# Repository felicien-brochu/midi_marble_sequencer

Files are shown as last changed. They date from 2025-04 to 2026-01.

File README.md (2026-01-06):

# MIDI Marble Sequencer

MIDI Marble Sequencer is a hardware + firmware project that detects marbles on IR sensor tracks and outputs MIDI over USB. The system is split into a main ESP-IDF firmware (sequencer + USB MIDI) and ESP32-based control boards (Arduino/PlatformIO) connected over I2C.

## Repository layout

- `hardware/` — CAD (SolidWorks parts/assemblies) and related manufacturing files.
- `software/`
	- `midi_marble_sequencer_main/` — main firmware (ESP-IDF) for the sequencer + USB MIDI.
	- `midi_marble_sequencer_controls_main/` — main control board firmware (PlatformIO/Arduino).
	- `midi_marble_sequencer_controls_pages/` — pages control board firmware (PlatformIO/Arduino).
	- `common_src/` — shared code used by the control board firmwares.
	- `smab_midi_mapper/` — JUCE utility app (see its README).
	- `stats/` — calibration/statistics data exports.

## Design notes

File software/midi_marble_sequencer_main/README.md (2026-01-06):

# MIDI Marble Sequencer — firmware (main)

Compact firmware for the MIDI Marble Sequencer. Runs on ESP-IDF and exposes a USB MIDI device while controlling sensor boards, control boards, and a sequencer engine.

## Highlights
- Real-time sequencer with 8 tracks × 32 eighth-note positions
- IR sensor-based marble color detection and calibration
- USB MIDI output via TinyUSB
- Control boards over I2C (main controls + pages)
- Calibrate IR sensors via dedicated calibration mode

## Requirements
- ESP-IDF v5.x
- C/C++ toolchain supported by ESP-IDF (esp-clang / xtensa)
- USB host supporting TinyUSB (configured in project)
- Connected hardware: IR sensor boards, control boards, calibration button, LEDs

Repo uses component manifest: espressif/esp_tinyusb and idf ^5.0

## Build & Flash (typical)
1. Install ESP-IDF v5 and toolchain following Espressif instructions.
2. From firmware directory (where this README.md lives):
    - idf.py build
    - idf.py -p /dev/ttyUSB0 flash monitor
    Replace serial port as needed.

## Calibration mode
To enter calibration:
1. Power OFF the device.
2. Power ON while holding the calibration button (back of the device).
3. Release the button when the device boots into calibration mode.

See calibration_README.md for detailed step-by-step instructions and measurement patterns.

## Usage
- Plug device into a host — it appears as a MIDI device.
- Use the hardware controls (play/pause, BPM potentiometer, page buttons, rotary buttons) to control playback and editing.
- Sequencer state and controls are managed by ControlBoardsController and Sequencer classes; MIDI mapping is handled by MidiMapper.

## Project layout (main)
- main/
  - Sequencer.* — sequencer logic and page management
  - MasterClock.* — timing and scheduling
  - MarbleDetector.* — detect marbles using thresholds
  - MidiController.*, MidiMapper.* — MIDI output and mapping
  - ControlBoardsController.* — I2C communications with control boards
  - calibration/ — calibration controller, display, storage, stats
  - IRSens* — IR sensor reading utilities
  - CMakeLists.txt, idf_component.yml, README.md

## Contributing
- Open PRs against main branch.
- Keep firmware changes modular and test with hardware where possible.

## License
Add a license file to the repo (e.g., MIT) if desired.

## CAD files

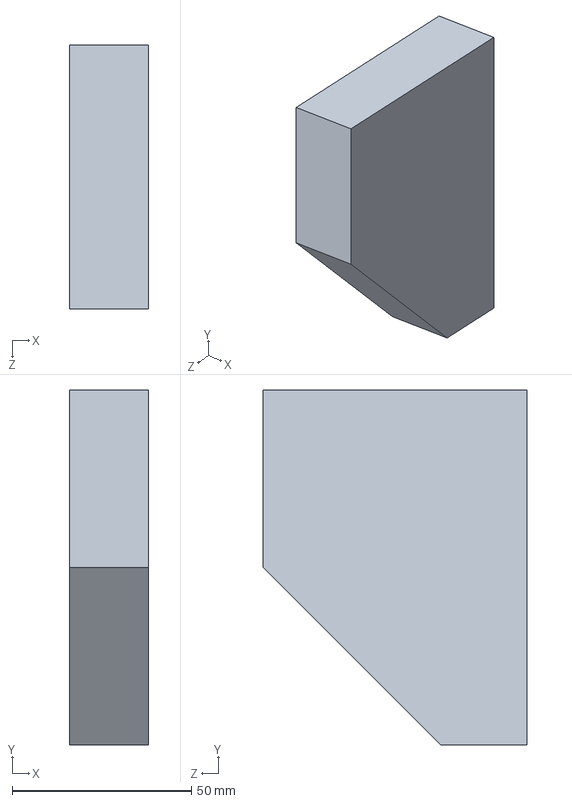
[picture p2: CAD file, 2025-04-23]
hardware/box/Equerre_trav_int_horiz_arriere^MIDI_marble_sequencer_box_Assemblage.SLDPRT
22.0 x 99.0 x 73.5 mm

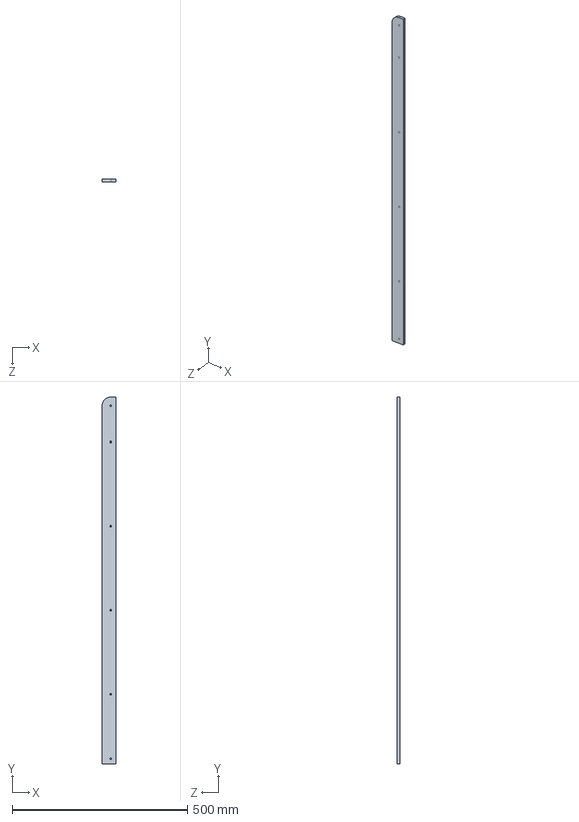
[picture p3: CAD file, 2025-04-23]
hardware/box/planche_avant^MIDI_marble_sequencer_box_Assemblage.SLDPRT
40.0 x 1047.5 x 8.00 mm

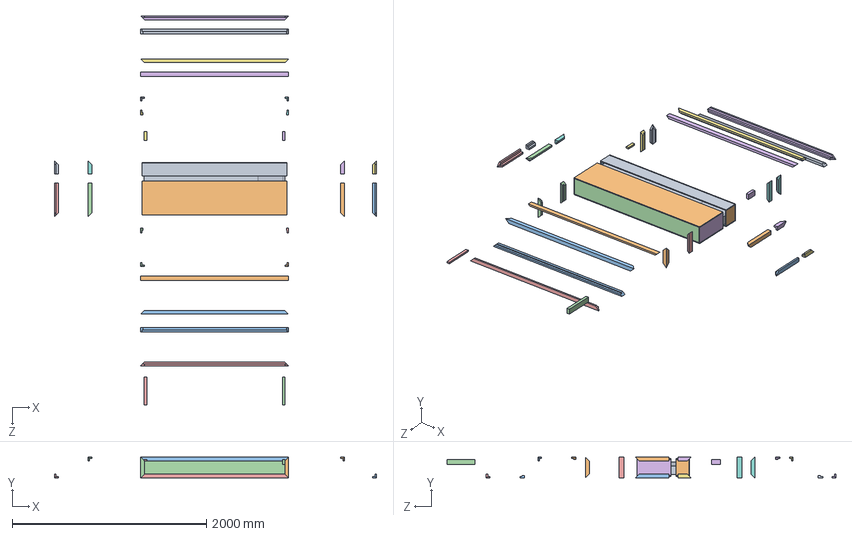
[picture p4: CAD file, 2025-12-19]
hardware/flightcase/midi_marble_sequencer_flight_case.SLDASM
3318.9 x 216.0 x 4009.3 mm
sequencer_dummy^midi_marble_sequencer_flight_case
corniere_av_m_av_d
corniere_av_l_av_h
corniere_av_m_av_g
corniere_av_l_av_b
corniere_ar_l_ar_b
corniere_ar_l_ar_h
corniere_ar_m_ar_d
corniere_ar_m_ar_g
bord_av_l_ar_h^midi_marble_sequencer_flight_case
bord_av_l_ar_b^midi_marble_sequencer_flight_case
bord_av_m_ar_g
bord_av_m_ar_d^midi_marble_sequencer_flight_case
bord_ar_l_av_h^midi_marble_sequencer_flight_case
bord_ar_m_av_g^midi_marble_sequencer_flight_case
bord_ar_m_av_d^midi_marble_sequencer_flight_case
bord_ar_l_av_b^midi_marble_sequencer_flight_case
corniere_arrete_av_t_d_h
corniere_arrete_av_t_d_b
corniere_arrete_av_t_g_h
corniere_arrete_av_t_g_b
corniere_arrete_ar_t_d_h
corniere_arrete_ar_t_d_b
corniere_arrete_ar_t_g_h
corniere_arrete_ar_t_g_b
panneau_av_h^midi_marble_sequencer_flight_case
panneau_av_b^midi_marble_sequencer_flight_case
panneau_av_av^midi_marble_sequencer_flight_case
panneau_av_g^midi_marble_sequencer_flight_case
panneau_av_d^midi_marble_sequencer_flight_case
panneau_ar_ar^midi_marble_sequencer_flight_case
panneau_ar_b^midi_marble_sequencer_flight_case
panneau_ar_h^midi_marble_sequencer_flight_case
panneau_ar_d^midi_marble_sequencer_flight_case
panneau_ar_g^midi_marble_sequencer_flight_case
maintien_av_d^midi_marble_sequencer_flight_case
maintien_av_g^midi_marble_sequencer_flight_case
maintien_ar_g^midi_marble_sequencer_flight_case
maintien_ar_d^midi_marble_sequencer_flight_case

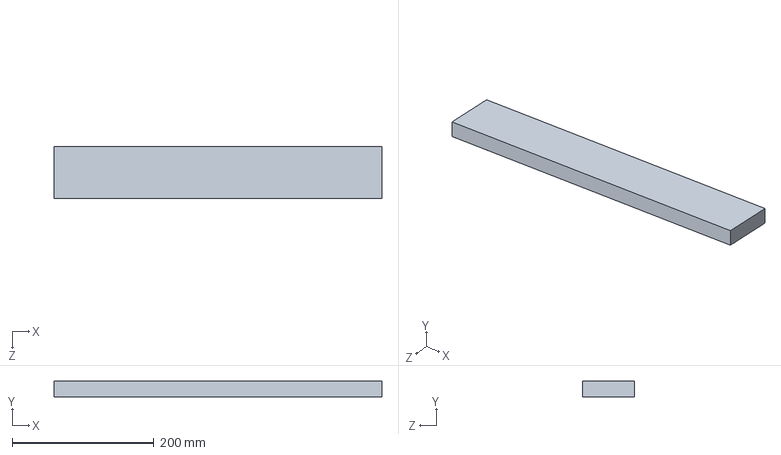
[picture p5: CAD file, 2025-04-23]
hardware/box/traverse_bac_a_bille_gauche^MIDI_marble_sequencer_box_Assemblage.SLDPRT
462.0 x 22.0 x 73.5 mm

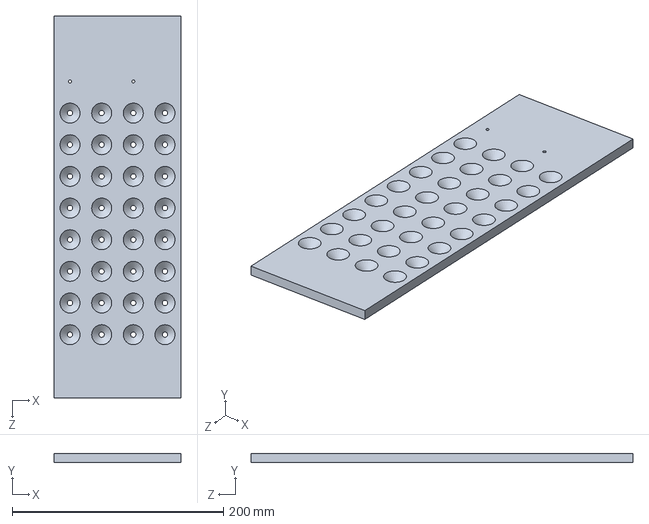
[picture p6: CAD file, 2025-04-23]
hardware/box/Planche_capteurs^MIDI_marble_sequencer_box_Assemblage.SLDPRT
120.0 x 8.50 x 362.0 mm

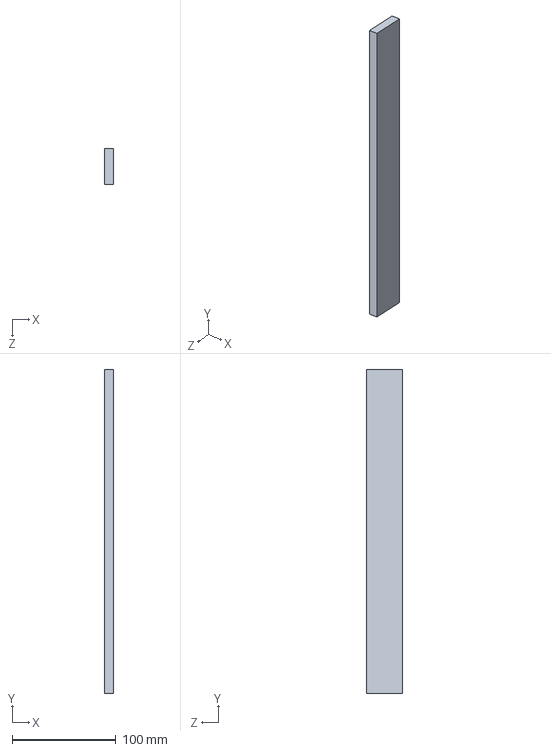
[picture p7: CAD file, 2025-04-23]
hardware/box/traverse_planche_capteurs^MIDI_marble_sequencer_box_Assemblage.SLDPRT
9.00 x 312.0 x 35.0 mm

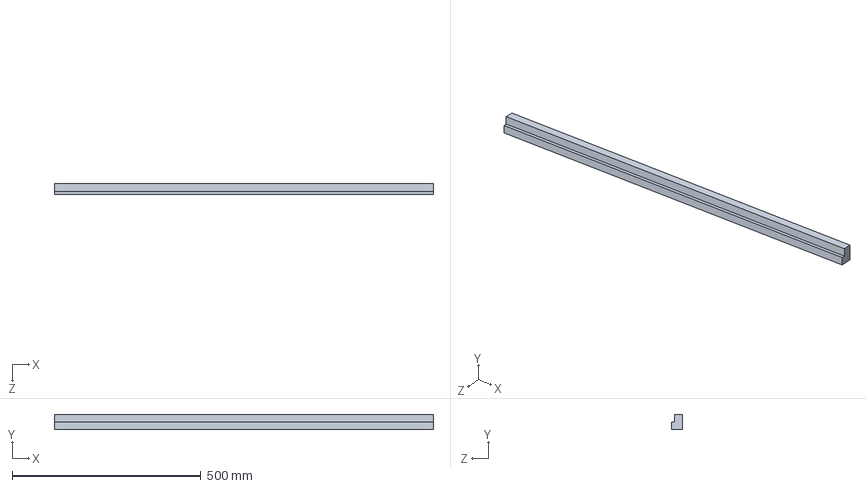
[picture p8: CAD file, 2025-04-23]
hardware/box/feuillure_avant^MIDI_marble_sequencer_box_Assemblage.SLDPRT
1005.0 x 40.0 x 30.0 mm

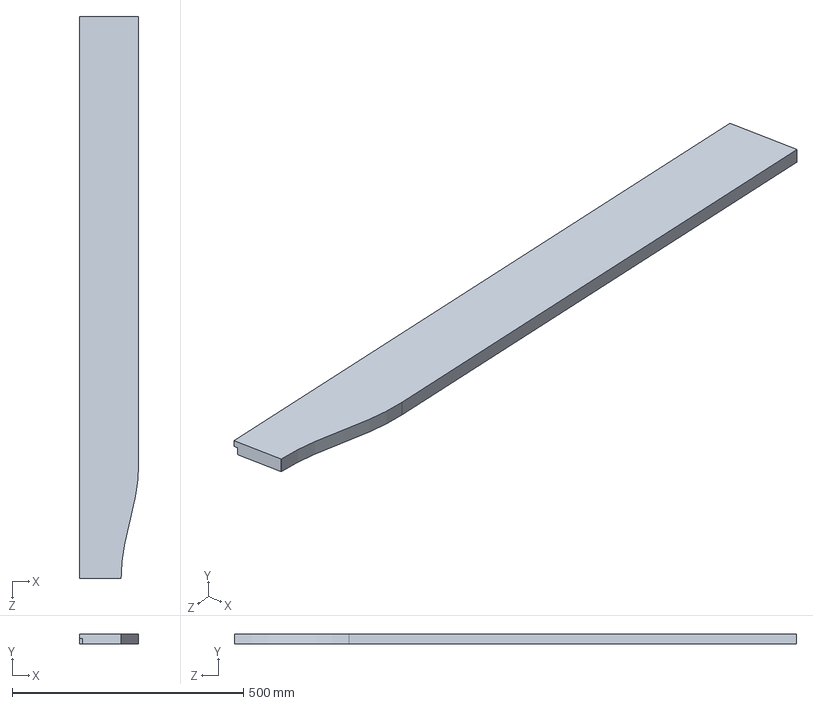
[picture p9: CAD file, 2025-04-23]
hardware/box/traverse_ext_arrière^MIDI_marble_sequencer_box_Assemblage.SLDPRT
128.5 x 22.0 x 1216.0 mm

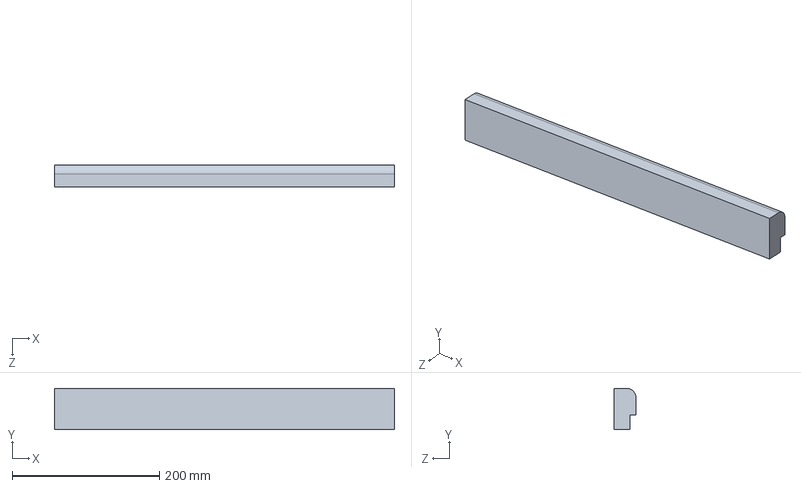
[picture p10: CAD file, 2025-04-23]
hardware/box/traverse_ext_feuillure_droite^MIDI_marble_sequencer_box_Assemblage.SLDPRT
462.0 x 56.0 x 30.0 mm

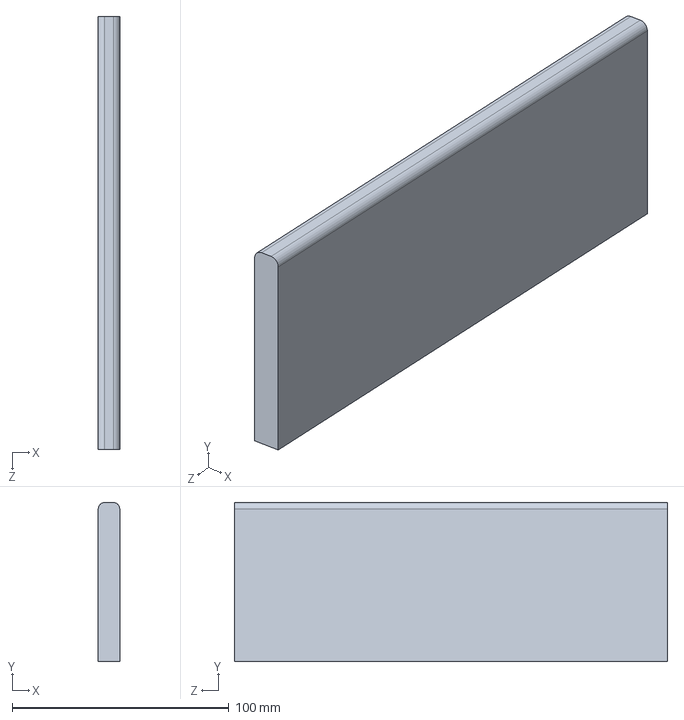
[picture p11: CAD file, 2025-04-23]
hardware/box/bac_a_billes_traverse_horiz^MIDI_marble_sequencer_box_Assemblage.SLDPRT
10.00 x 73.5 x 200.0 mm

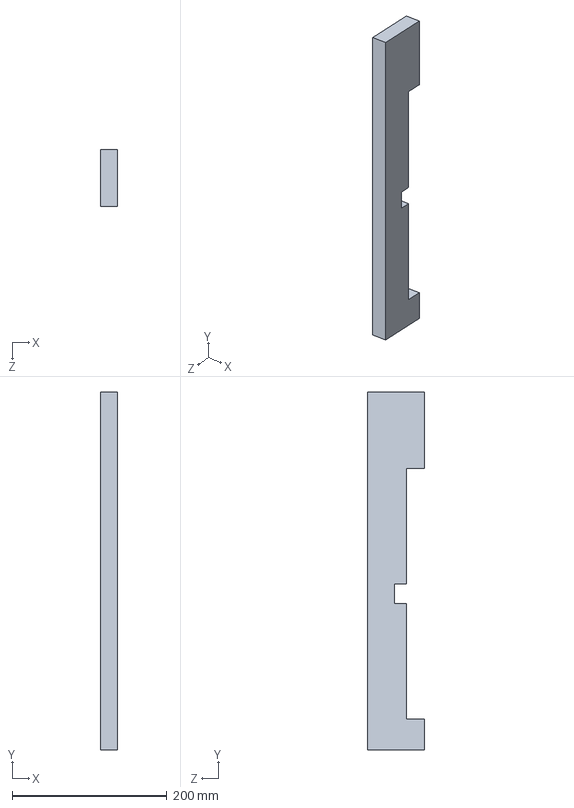
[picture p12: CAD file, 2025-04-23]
hardware/box/Copie de traverse_int_vert_gauche_vraie_traverse^MIDI_marble_sequencer_box_Assemblage.SLDPRT
22.0 x 462.0 x 73.5 mm

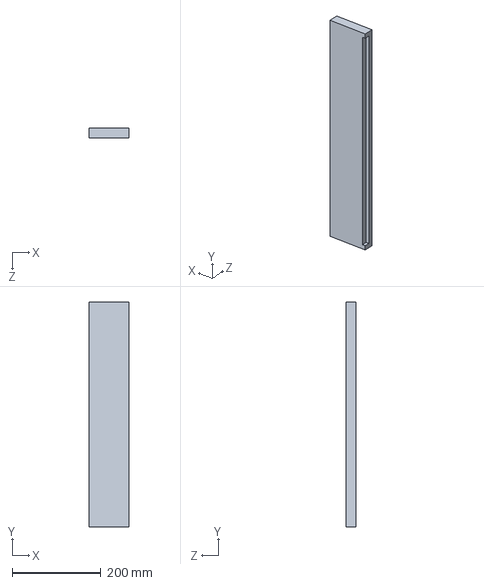
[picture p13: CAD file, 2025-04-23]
hardware/box/traverse_ext_droite^MIDI_marble_sequencer_box_Assemblage.SLDPRT
90.5 x 506.0 x 22.0 mm

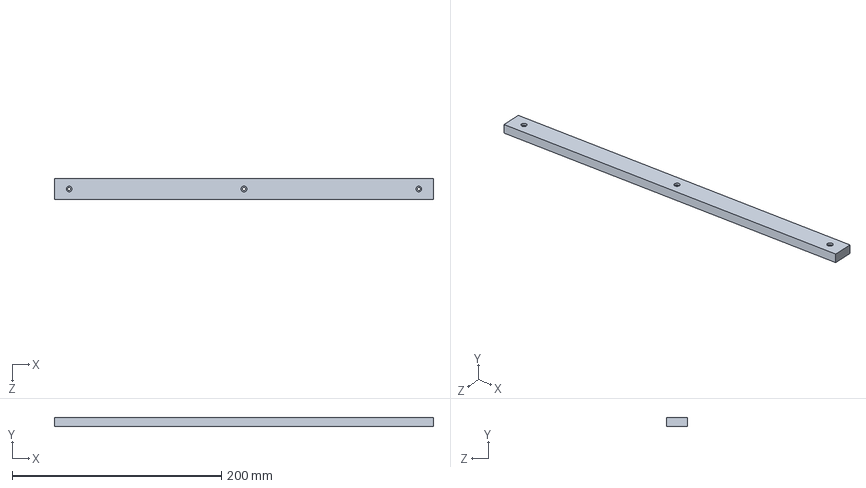
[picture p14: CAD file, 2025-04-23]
hardware/box/rallonge_droite^MIDI_marble_sequencer_box_Assemblage.SLDPRT
362.0 x 8.50 x 20.0 mm

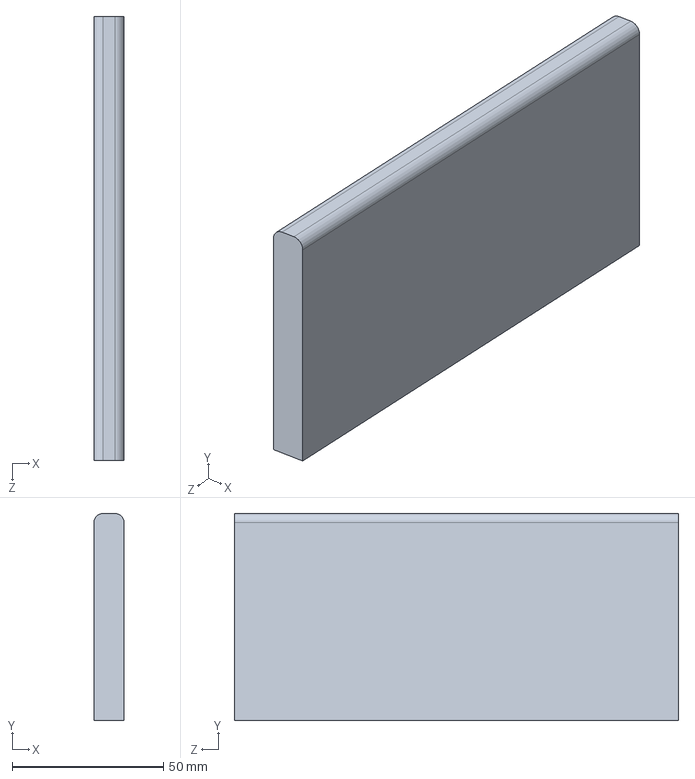
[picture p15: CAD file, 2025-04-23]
hardware/box/bac_a_billes_traverse_vert^MIDI_marble_sequencer_box_Assemblage.SLDPRT
10.00 x 68.5 x 147.0 mm

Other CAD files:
hardware/box/PCB_main.SLDPRT
hardware/box/feuillure_gauche_longue^MIDI_marble_sequencer_box_Assemblage.SLDPRT
hardware/box/traverse_arrière_int^MIDI_marble_sequencer_box_Assemblage.SLDPRT
hardware/box/traverse_int_vert_gauche_vraie_traverse^MIDI_marble_sequencer_box_Assemblage.SLDPRT
hardware/box/Bouton_BPM.SLDPRT
hardware/box/Bouton_buis_cylindre.SLDPRT
hardware/box/Bouton_play_stop.DXF
hardware/box/Bouton_play_stop.SLDPRT
hardware/box/Cadre_gauche.SLDDRW
hardware/box/Cadre_gauche^MIDI_marble_sequencer_box_Assemblage.SLDPRT
hardware/box/Débit général structure.SLDDRW
hardware/box/MIDI_marble_sequencer_box_Assemblage.SLDASM
hardware/box/PCB_channel_select.SLDPRT
hardware/box/PCB_control.SLDPRT
hardware/box/PCB_ir_sensor_board.SLDPRT
hardware/box/PCB_tracks_select.SLDPRT
hardware/box/Planche_capteurs^MIDI_marble_sequencer_box_Assemblage.SLDDRW
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

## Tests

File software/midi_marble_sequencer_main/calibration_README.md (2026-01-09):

# Calibration Procedure

This guide explains how to calibrate the IR sensors for the MIDI Marble Sequencer.

## Overview

The calibration process measures the IR sensor response for different marble colors to establish accurate detection thresholds. This ensures reliable marble detection during operation.

## Starting Calibration Mode

1. **Power off** the device
3. **Power on** the device while **holding the calibration button** (the calibration button is at the back of the sequencer)
4. **Release** the button once the device starts

The device will enter calibration mode instead of normal operation.

## Board Calibration Phase

Before the main sensor calibration begins, you'll need to complete a board calibration phase. This phase ensures that all IR sensor boards have their potentiometers properly adjusted for optimal performance.

### What You Need
- **1 Brown marble** (for sensor 0)
- **1 Blue marble** (for sensor 15)

### How It Works

The board calibration phase uses LED feedback to help you adjust each board's potentiometer:

1. **LED Indicators:**
   - The **BeatsLEDSnake** shows which board is currently selected (one LED lit)
   - **Top LED line** (played_pages_led): Shows the brown marble reading on sensor 0
   - **Bottom LED line** (edited_pages_led): Shows the blue marble reading on sensor 15

2. **LED Feedback Pattern:**
   - **LED 0:** Value too low (below acceptable range)
   - **LEDs 1, 2, or 3:** Approaching target from below
   - **LEDs 3 and 4 (both):** Perfect! Value is on target ✓
   - **LEDs 4, 5, or 6:** Moving away from target toward upper limit
   - **LED 7:** Value too high (above acceptable range)

3. **Target Values:**
   - **Brown marble (sensor 0):** Target = 450, Acceptable range [250, 650]
   - **Blue marble (sensor 15):** Target = 2400, Acceptable range [2000, 2800]

### Step-by-Step Instructions

1. **Place the Marbles**
   - Place a **brown marble** on **sensor 0** of the selected board
   - Place a **blue marble** on **sensor 15** of the selected board

2. **Adjust the Potentiometer**
   - Watch the LED lines for feedback
   - Turn the board's potentiometer until **both LED lines show LEDs 3 and 4 lit together**
   - This indicates optimal calibration for both sensors

3. **Move to Next Board**
   - **Short press** the calibration button to select the next board
   - The BeatsLEDSnake LED will move to indicate the newly selected board
   - Sensor values for the newly selected board will be logged to console

4. **Repeat for All Boards**
   - Repeat steps 1-3 for all 16 boards
   - You can cycle through boards as many times as needed to fine-tune adjustments

5. **Complete Board Calibration**
   - Once all boards are calibrated, **press and hold** the calibration button for **5 seconds**
   - The system will wait for the button to be released, then proceed to sensor calibration

## Sensor Calibration Process

### What You Need
- **32 marbles of each color** (160 marbles total):
  - 32 Brown marbles
  - 32 Orange marbles
  - 32 Green marbles
  - 32 Blue marbles
  - 32 White marbles

### First Cycle Setup Example

Here's what the first calibration cycle looks like on your device:

```
        ┌─ Eighth Note Positions 0→31 (Left to Right)  ─┐
        │                                               │
Track 0 │ [  ][  ][  ][  ][  ][  ][  ][  ] ... [  ][  ] │ ← Empty (no marbles)
Track 1 │ [Br][Br][Br][Br][Br][Br][Br][Br] ... [Br][Br] │ ← 32 Brown marbles
Track 2 │ [Or][Or][Or][Or][Or][Or][Or][Or] ... [Or][Or] │ ← 32 Orange marbles
Track 3 │ [Gr][Gr][Gr][Gr][Gr][Gr][Gr][Gr] ... [Gr][Gr] │ ← 32 Green marbles
Track 4 │ [Bl][Bl][Bl][Bl][Bl][Bl][Bl][Bl] ... [Bl][Bl] │ ← 32 Blue marbles
Track 5 │ [Wh][Wh][Wh][Wh][Wh][Wh][Wh][Wh] ... [Wh][Wh] │ ← 32 White marbles
Track 6 │ [  ][  ][  ][  ][  ][  ][  ][  ] ... [  ][  ] │ ← Empty (no marbles)
Track 7 │ [  ][  ][  ][  ][  ][  ][  ][  ] ... [  ][  ] │ ← Empty (no marbles)
        └───────────────────────────────────────────────┘
```

In subsequent cycles, the pattern shifts up by one track (Track 1 → Track 0, Track 2 → Track 1, etc.).

### Step-by-Step Instructions

The calibration process runs 64 measurement cycles. For each cycle, place marbles according to the LEDs (or console table), start the measurement, wait for completion, then rearrange for the next cycle.

1. **Check the Current Cycle Placement**
    - Place marbles on tracks with a lit LED, leave other tracks empty
    - **Optional - Console Output:** If you have console access, it displays the exact color per track:
     ```
     |    0   |    1   |    2   |    3   |    4   |    5   |    6   |    7   |
   | NONE   | Brown  | Orange | Green  | Blue   | White  | NONE   | NONE   |
     Measure 1/64
     ```

2. **Place the Marbles**
   - For each track with a lit LED, place one marble on every sensor
   - **Color assignment pattern:** Brown → Orange → Green → Blue → White; 3 tracks are always empty
   - On the first cycle: Track 1 gets Brown, Track 2 gets Orange, Track 3 gets Green, Track 4 gets Blue, Track 5 gets White (Tracks 0, 6, 7 are empty)

3. **Confirm Placement**
   - **Press the calibration button once** when marbles are correctly placed
   - Wait for the measurement to complete - the control board display will update to show progress

4. **Repeat for All Cycles**
   - After each measurement completes, the firmware advances to the next cycle and updates the LEDs for the next arrangement. If the LED pattern did not change, rotate the marbles on the same track (see: Rotating Marbles Within the Same Track). If the LED pattern changed, Rearrange marbles to match the new LED pattern (see: Shifting Marbles Between Tracks)

### Rotating Marbles Within the Same Track

```
Before rotation (Current cycle measurement complete):
Track 0 │ [Br][Br][Br][Br][Br][Br][Br][Br] ... [Br][Br] │
          ↓   ↓   ↓   ↓   ↓   ↓   ↓   ↓         ↓   ↓
          Move all marbles one position to the left 
          The leftmost marble wraps around to the right

After rotation (Ready for next cycle):
Track 0 │ [Br][Br][Br][Br][Br][Br][Br][Br] ... [Br][Br] │
```

**Why rotate?** This ensures different individual marbles are tested at each sensor position, accounting for physical variations between marbles of the same color.

### Shifting Marbles Between Tracks

When the color pattern rotates to the next cycle, you need to shift marbles between tracks:

```
Cycle 1 - Initial setup:
Track 0 │ [  ][  ][  ][  ][  ][  ][  ][  ] ... [  ][  ] │ ← Empty
Track 1 │ [Br][Br][Br][Br][Br][Br][Br][Br] ... [Br][Br] │ ← Brown
Track 2 │ [Or][Or][Or][Or][Or][Or][Or][Or] ... [Or][Or] │ ← Orange
Track 3 │ [Gr][Gr][Gr][Gr][Gr][Gr][Gr][Gr] ... [Gr][Gr] │ ← Green
Track 4 │ [Bl][Bl][Bl][Bl][Bl][Bl][Bl][Bl] ... [Bl][Bl] │ ← Blue
Track 5 │ [Wh][Wh][Wh][Wh][Wh][Wh][Wh][Wh] ... [Wh][Wh] │ ← White
Track 6 │ [  ][  ][  ][  ][  ][  ][  ][  ] ... [  ][  ] │ ← Empty
Track 7 │ [  ][  ][  ][  ][  ][  ][  ][  ] ... [  ][  ] │ ← Empty
          ↓ Colors shift UP one track; empty tracks also shift ↓

Cycle 2 - After shifting:
Track 0 │ [Br][Br][Br][Br][Br][Br][Br][Br] ... [Br][Br] │ ← Brown (was Track 1)
Track 1 │ [Or][Or][Or][Or][Or][Or][Or][Or] ... [Or][Or] │ ← Orange (was Track 2)
Track 2 │ [Gr][Gr][Gr][Gr][Gr][Gr][Gr][Gr] ... [Gr][Gr] │ ← Green (was Track 3)
Track 3 │ [Bl][Bl][Bl][Bl][Bl][Bl][Bl][Bl] ... [Bl][Bl] │ ← Blue (was Track 4)
Track 4 │ [Wh][Wh][Wh][Wh][Wh][Wh][Wh][Wh] ... [Wh][Wh] │ ← White (was Track 5)
Track 5 │ [  ][  ][  ][  ][  ][  ][  ][  ] ... [  ][  ] │ ← Empty (was Track 6)
Track 6 │ [  ][  ][  ][  ][  ][  ][  ][  ] ... [  ][  ] │ ← Empty (was Track 7)
Track 7 │ [  ][  ][  ][  ][  ][  ][  ][  ] ... [  ][  ] │ ← Empty (was Track 0)
```

## Saving Calibration Data

After all measurements are complete:

1. **Confirm Save**
   - The console will prompt: `Save calibration data? Press button for 5 seconds to confirm.`
   - **Press and hold** the calibration button for **5 seconds** to save
   - Release early to cancel without saving

2. **Completion**
   - If saved successfully, the console will prompt: `Calibration data saved successfuly.`
   - The completion rate display will show 100%

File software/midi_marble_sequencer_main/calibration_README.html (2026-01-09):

# Calibration Procedure

This guide explains how to calibrate the IR sensors for the MIDI Marble Sequencer.

## Overview

The calibration process measures the IR sensor response for different marble colors to establish accurate detection thresholds. This ensures reliable marble detection during operation.

## Starting Calibration Mode

1. Power off the device
2. Power on the device while holding the calibration button (the calibration button is at the back of the sequencer)
3. Release the button once the device starts

The device will enter calibration mode instead of normal operation.

## Board Calibration Phase

Before the main sensor calibration begins, you'll need to complete a board calibration phase. This phase ensures that all IR sensor boards have their potentiometers properly adjusted for optimal performance.

### What You Need

- 1 Brown marble (for sensor 0)
- 1 Blue marble (for sensor 15)

Brown
Sensor 0

Blue
Sensor 15

### How It Works

The board calibration phase uses LED feedback to help you adjust each board's potentiometer:

#### LED Indicators:

- The BeatsLEDSnake shows which board is currently selected (one LED lit)
- Top LED line (played_pages_led): Shows the brown marble reading on sensor 0
- Bottom LED line (edited_pages_led): Shows the blue marble reading on sensor 15

#### LED Feedback Pattern:

- LED 0: Value too low (below acceptable range)
- LEDs 1, 2, or 3: Approaching target from below
- LEDs 3 and 4 (both): Perfect! Value is on target ✓
- LEDs 4, 5, or 6: Moving away from target toward upper limit
- LED 7: Value too high (above acceptable range)

#### Target Values:

- Brown marble (sensor 0): Target = 450, Acceptable range [250, 650]
- Blue marble (sensor 15): Target = 2400, Acceptable range [2000, 2800]

### Step-by-Step Instructions

#### 1Place the Marbles

- Place a brown marble on sensor 0 of the selected board
- Place a blue marble on sensor 15 of the selected board

#### 2Adjust the Potentiometer

- Watch the LED lines for feedback
- Turn the board's potentiometer until both LED lines show LEDs 3 and 4 lit together
- This indicates optimal calibration for both sensors

#### 3Move to Next Board

- Short press the calibration button to select the next board
- The BeatsLEDSnake LED will move to indicate the newly selected board
- Sensor values for the newly selected board will be logged to console

#### 4Repeat for All Boards

- Repeat steps 1-3 for all 16 boards
- You can cycle through boards as many times as needed to fine-tune adjustments

#### 5Complete Board Calibration

- Once all boards are calibrated, press and hold the calibration button for 5 seconds
- The system will wait for the button to be released, then proceed to sensor calibration

## Sensor Calibration Process

### What You Need

32 marbles of each color (160 marbles total):

- 32 Brown marbles
- 32 Orange marbles
- 32 Green marbles
- 32 Blue marbles
- 32 White marbles

Brown

Orange

Green

Blue

White

### First Cycle Setup Example

Here's what the first calibration cycle looks like on your device:

← Eighth Note Positions 0→31 (Left to Right) →

Track 0

Empty

Track 1

32 Brown

Track 2

32 Orange

Track 3

32 Green

Track 4

32 Blue

Track 5

32 White

Track 6

Empty

Track 7

Empty

### Step-by-Step Instructions

The calibration process runs 64 measurement cycles. For each cycle, place marbles according to the LEDs (or console table), start the measurement, wait for completion, then rearrange for the next cycle.

#### 1Check the Current Cycle Placement

- Place marbles on lit tracks (0-7); leave unlit tracks empty

Optional - Console Output: If you have console access, it displays the exact color per track:

|    0   |    1   |    2   |    3   |    4   |    5   |    6   |    7   |
| NONE   | Brown  | Orange | Green  | Blue   | White  | NONE   | NONE   |
Measure 1/64

#### 2Place the Marbles

- For each track with a lit LED, place one marble on every sensor
- Color assignment pattern: colors rotate across tracks (Brown → Orange → Green → Blue → White); 3 tracks are always empty
- On the first cycle: Track 1 gets Brown, Track 2 gets Orange, Track 3 gets Green, Track 4 gets Blue, Track 5 gets White (Tracks 0, 6, 7 are empty)

#### 3Confirm Placement

- Press the calibration button once when marbles are correctly placed
- Wait for the measurement to complete - the control board display will update to show progress

#### 4Repeat for All Cycles

- After each measurement completes, the firmware advances to the next cycle and updates the LEDs for the next arrangement. If the LED pattern did not change, rotate the marbles on the same track (see: Rotating Marbles Within the Same Track). If the LED pattern changed, Rearrange marbles to match the new LED pattern (see: Shifting Marbles Between Tracks)

### Rotating Marbles Within the Same Track

Instead of removing marbles between cycles when the LED pattern is unchanged, rotate them one position left so each sensor sees a different marble. The leftmost marble (sensor 0) wraps around to sensor 31.

#### Rotation schematic (one-position left shift)

Visual mapping of marble movement: each marble moves one sensor to the left; the marble at sensor 0 wraps to sensor 31.

Why rotate? This ensures different individual marbles are tested at each sensor position, accounting for physical variations between marbles of the same color.

### Shifting Marbles Between Tracks

When the color pattern rotates to the next cycle, the entire pattern shifts up one track.

#### Cycle 1 - Initial Setup:

Track 0

Empty

Track 1

Brown

Track 2

Orange

Track 3

Green

Track 4

Blue

Track 5

White

Track 6

Empty

Track 7

Empty

↓ Everything shifts UP one track (Track 1 → Track 0) ↓

#### Cycle 2 - After Shifting:

Track 0

Brown (was Track 1)

Track 1

Orange (was Track 2)

Track 2

Green (was Track 3)

Track 3

Blue (was Track 4)

Track 4

White (was Track 5)

Track 5

Empty (was Track 6)

Track 6

Empty (was Track 7)

Track 7

Empty (was Track 0)

## Saving Calibration Data

After all measurements are complete:

#### 1Confirm Save

The console will prompt: Save calibration data? Press button for 5 seconds to confirm.

- Press and hold the calibration button for 5 seconds to save
- Release early to cancel without saving

#### 2Completion

- If saved successfully, the console will prompt: Calibration data saved successfuly.
- The completion rate display will show 100%

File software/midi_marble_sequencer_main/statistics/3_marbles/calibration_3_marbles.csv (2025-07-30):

board | sensor | marble_color | min_value | max_value | mean | low_threshold | high_threshold
0 | 0 | NONE | 24 | 134 | 69 | 0 | 613
0 | 0 | Orange | 1093 | 1355 | 1210 | 613 | 1712
0 | 0 | Green | 2070 | 2244 | 2137 | 1712 | 3008
0 | 0 | White | 3773 | 3796 | 3785 | 3008 | 4095
0 | 1 | NONE | 29 | 154 | 88 | 0 | 551
0 | 1 | Orange | 948 | 1121 | 1032 | 551 | 1401
0 | 1 | Green | 1682 | 1883 | 1783 | 1401 | 2795
0 | 1 | White | 3707 | 3749 | 3726 | 2795 | 4095
0 | 2 | NONE | 70 | 158 | 118 | 0 | 495
0 | 2 | Orange | 832 | 980 | 912 | 495 | 1229
0 | 2 | Green | 1478 | 1639 | 1543 | 1229 | 2300
0 | 2 | White | 2961 | 3279 | 3200 | 2300 | 4095
0 | 3 | NONE | 5 | 71 | 22 | 0 | 453
0 | 3 | Orange | 836 | 976 | 913 | 453 | 1261
0 | 3 | Green | 1547 | 1657 | 1592 | 1261 | 2558
0 | 3 | White | 3459 | 3671 | 3543 | 2558 | 4095
0 | 4 | NONE | 11 | 59 | 28 | 0 | 422
0 | 4 | Orange | 785 | 934 | 878 | 422 | 1174
0 | 4 | Green | 1414 | 1590 | 1511 | 1174 | 2437
0 | 4 | White | 3284 | 3422 | 3359 | 2437 | 4095
0 | 5 | NONE | 70 | 185 | 109 | 0 | 419
0 | 5 | Orange | 653 | 767 | 703 | 419 | 979
0 | 5 | Green | 1191 | 1298 | 1246 | 979 | 1819
0 | 5 | White | 2340 | 2636 | 2579 | 1819 | 4095
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

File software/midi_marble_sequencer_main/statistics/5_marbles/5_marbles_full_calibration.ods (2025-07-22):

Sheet: 5_marbles_full_calibration
board | sensor | marble_color | min_value | max_value | low_threshold | high_threshold | mean |  | Somme interval | mean interval
0 | 0 | NONE | 0 | 22 | 0 | 576 | 0 | NONE | 3857 | 15,06640625
0 | 0 | Orange | 1131 | 1350 | 576 | 1566 | 1215 | Orange | 40295 | 157,40234375
0 | 0 | Red | 1651 | 1773 | 1566 | 1882 | 1704 | Red | 27117 | 105,92578125
0 | 0 | Green | 2029 | 2176 | 1882 | 2443 | 2121 | Green | 37019 | 144,60546875
0 | 0 | Blue | 2997 | 3184 | 2443 | 3451 | 3111 | Blue | 40288 | 157,375
0 | 0 | White | 3719 | 3732 | 3451 | 4095 | 3727 | White | 26701 | 104,30078125
0 | 1 | NONE | 0 | 41 | 0 | 519 | 3
0 | 1 | Orange | 998 | 1057 | 519 | 1142 | 1029
0 | 1 | Red | 1397 | 1569 | 1142 | 1712 | 1481
0 | 1 | Green | 1805 | 1905 | 1712 | 2074 | 1862
0 | 1 | Blue | 2503 | 2759 | 2074 | 3204 | 2612
0 | 1 | White | 3650 | 3694 | 3204 | 4095 | 3686
0 | 2 | NONE | 0 | 81 | 0 | 431 | 13
0 | 2 | Orange | 782 | 945 | 431 | 1074 | 869
0 | 2 | Red | 1170 | 1311 | 1074 | 1391 | 1226
0 | 2 | Green | 1465 | 1607 | 1391 | 1833 | 1543
0 | 2 | Blue | 2068 | 2174 | 1833 | 2641 | 2134
0 | 2 | White | 3108 | 3313 | 2641 | 4095 | 3223
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

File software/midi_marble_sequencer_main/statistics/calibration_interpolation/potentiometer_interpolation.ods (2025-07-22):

 | brown | orange | red | green | blue | white
 | 5 | 447 | 705 | 911 | 1370 | 2222
 | 52 | 509 | 767 | 1019 | 1506 | 2412
 | 99 | 572 | 847 | 1095 | 1684 | 2613
 | 149 | 610 | 940 | 1176 | 1817 | 2780
 | 199 | 672 | 1009 | 1335 | 2010 | 3030
 | 245 | 780 | 1093 | 1438 | 2130 | 3275
 | 300 | 890 | 1246 | 1580 | 2260 | 3300
 | 345 | 957 | 1317 | 1639 | 2380 | 3278
 | 398 | 997 | 1462 | 1801 | 2715 | 3234
 | 452 | 1108 | 1512 | 1982 | 2792 | 3205
 | 505 | 1195 | 1668 | 2190 | 3058 | 3125
 | 552 | 1300 | 1844 | 2292 | 3057 | 3130
 | 642 | 1404 | 2016 | 2507 | 3050 | 3104
 | 745 | 1522 | 2176 | 2650 | 3130 | 3170
 | 844 | 1642 | 2217 | 2909 | 3055 | 3096
 | 952 | 1831 | 2533 | 2917 | 2967 | 3008
 | 1050 | 2013 | 2720 | 2892 | 2928 | 2955
 | 1217 | 2227 | 2865 | 2923 | 2958 | 2985
 | 1426 | 2601 | 2762 | 2812 | 2847 | 2865
 | 1493 | 2702 | 2756 | 2765 | 2790 | 2825
 | brown | orange | red | green | blue | white | red prev
 | 5 | 447 | 705 | 911 | 1370 | 2222 | 709,725152692948 |  |  |  |  |  |  |  | Régression |  |  |  |  |  |  | Régression |  |  |  |  | Régression |  |  |  |  | Régression |  |  |  |  | Régression
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

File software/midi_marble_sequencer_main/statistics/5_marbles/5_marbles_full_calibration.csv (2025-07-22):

board | sensor | marble_color | min_value | max_value | low_threshold | high_threshold
0 | 0 | NONE | 0 | 22 | 0 | 576
0 | 0 | Orange | 1131 | 1350 | 576 | 1566
0 | 0 | Red | 1651 | 1773 | 1566 | 1882
0 | 0 | Green | 2029 | 2176 | 1882 | 2443
0 | 0 | Blue | 2997 | 3184 | 2443 | 3451
0 | 0 | White | 3719 | 3732 | 3451 | 4095
0 | 1 | NONE | 0 | 41 | 0 | 519
0 | 1 | Orange | 998 | 1057 | 519 | 1142
0 | 1 | Red | 1397 | 1569 | 1142 | 1712
0 | 1 | Green | 1805 | 1905 | 1712 | 2074
0 | 1 | Blue | 2503 | 2759 | 2074 | 3204
0 | 1 | White | 3650 | 3694 | 3204 | 4095
0 | 2 | NONE | 0 | 81 | 0 | 431
0 | 2 | Orange | 782 | 945 | 431 | 1074
0 | 2 | Red | 1170 | 1311 | 1074 | 1391
0 | 2 | Green | 1465 | 1607 | 1391 | 1833
0 | 2 | Blue | 2068 | 2174 | 1833 | 2641
0 | 2 | White | 3108 | 3313 | 2641 | 4095
0 | 3 | NONE | 0 | 0 | 0 | 372
0 | 3 | Orange | 745 | 963 | 372 | 1106
0 | 3 | Red | 1188 | 1317 | 1106 | 1415
0 | 3 | Green | 1513 | 1632 | 1415 | 1728
0 | 3 | Blue | 2111 | 2338 | 1728 | 2917
0 | 3 | White | 3497 | 3633 | 2917 | 4095
0 | 4 | NONE | 0 | 0 | 0 | 394
0 | 4 | Orange | 789 | 940 | 394 | 1060
0 | 4 | Red | 1134 | 1213 | 1060 | 1284
0 | 4 | Green | 1422 | 1537 | 1284 | 1824
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

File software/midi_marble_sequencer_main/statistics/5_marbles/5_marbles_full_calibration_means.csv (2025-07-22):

none | orange | red | green | blue | white
0 | 1215 | 1704 | 2121 | 3111 | 3727
3 | 1029 | 1481 | 1862 | 2612 | 3686
13 | 869 | 1226 | 1543 | 2134 | 3223
0 | 879 | 1236 | 1594 | 2261 | 3572
0 | 853 | 1187 | 1472 | 2156 | 3322
13 | 682 | 969 | 1183 | 1651 | 2563
5 | 638 | 896 | 1120 | 1532 | 2336
0 | 814 | 1102 | 1384 | 1990 | 3155
0 | 911 | 1255 | 1612 | 2335 | 3569
0 | 827 | 1162 | 1455 | 2088 | 3216
1 | 673 | 966 | 1205 | 1731 | 2657
0 | 702 | 1005 | 1305 | 1849 | 2924
0 | 910 | 1226 | 1616 | 2304 | 3534
0 | 842 | 1216 | 1523 | 2148 | 3260
0 | 881 | 1276 | 1638 | 2331 | 3556
0 | 885 | 1194 | 1468 | 2125 | 3246
11 | 1389 | 1836 | 2308 | 3297 | 3711
1 | 1129 | 1599 | 1991 | 2850 | 3686
10 | 1191 | 1684 | 2123 | 3007 | 3686
0 | 1274 | 1741 | 2280 | 3253 | 3700
0 | 1035 | 1431 | 1796 | 2628 | 3657
2 | 856 | 1218 | 1513 | 2155 | 3330
1 | 977 | 1324 | 1654 | 2375 | 3566
0 | 969 | 1382 | 1737 | 2522 | 3645
1 | 1060 | 1477 | 1888 | 2696 | 3664
0 | 892 | 1242 | 1574 | 2205 | 3377
1 | 853 | 1198 | 1501 | 2149 | 3309
1 | 951 | 1298 | 1636 | 2331 | 3517
1 | 965 | 1348 | 1735 | 2467 | 3611
2 | 990 | 1401 | 1731 | 2488 | 3606
0 | 992 | 1391 | 1734 | 2428 | 3628
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

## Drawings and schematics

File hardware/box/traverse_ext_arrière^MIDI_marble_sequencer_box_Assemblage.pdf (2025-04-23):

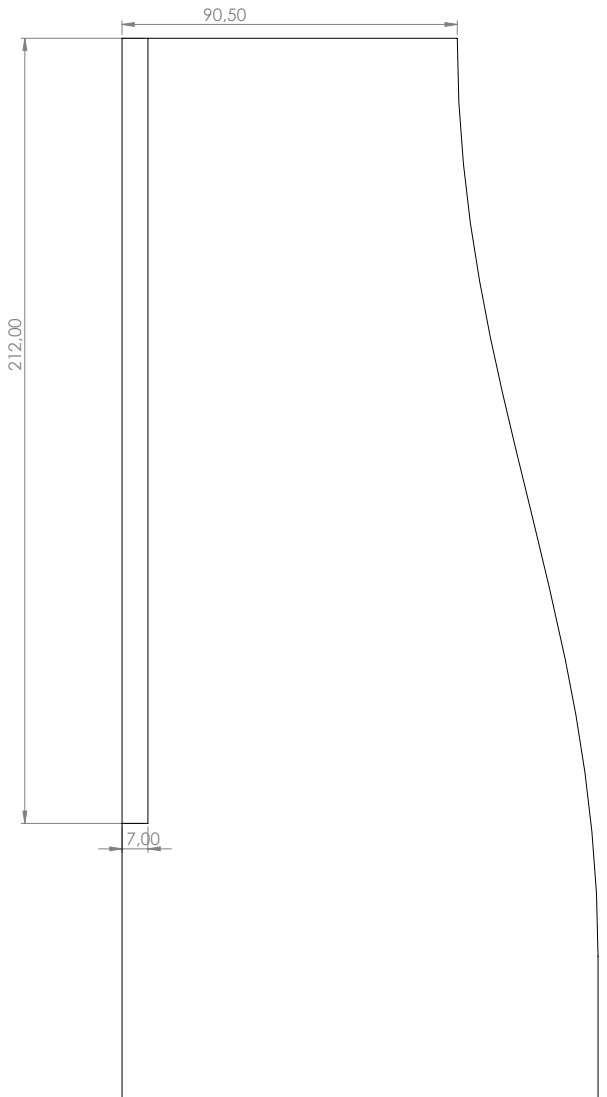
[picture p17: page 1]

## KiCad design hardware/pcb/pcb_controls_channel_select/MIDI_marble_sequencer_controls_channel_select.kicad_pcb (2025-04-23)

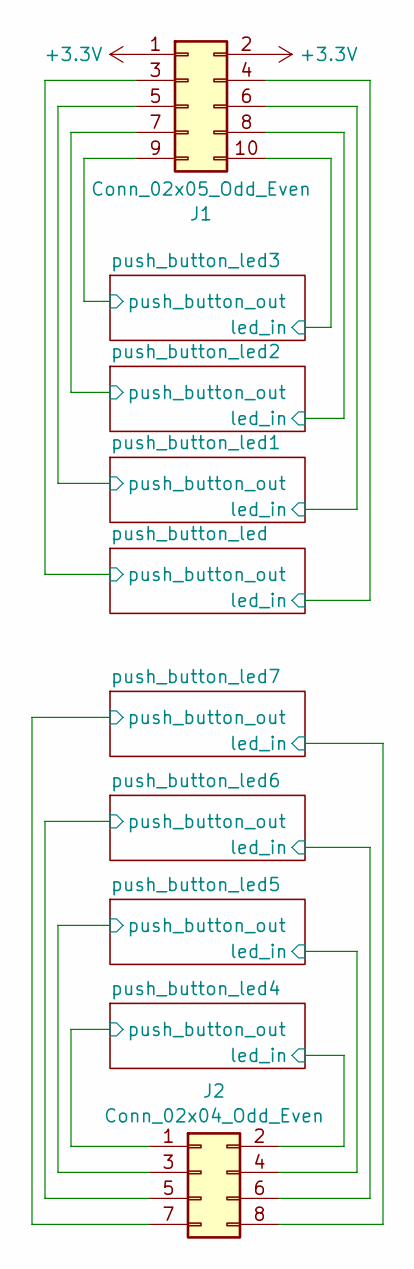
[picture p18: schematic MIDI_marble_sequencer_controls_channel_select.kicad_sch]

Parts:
J1: Conn_02x05_Odd_Even; PinHeader_2x05_P2.54mm_Vertical
J2: Conn_02x04_Odd_Even; PinHeader_2x04_P2.54mm_Vertical

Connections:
+3.3V: J1.1, J1.2; also elsewhere on the board
/push_button_led1/led_in: J1.6; also elsewhere on the board
/push_button_led1/push_button_out: J1.5; also elsewhere on the board
/push_button_led2/led_in: J1.8; also elsewhere on the board
/push_button_led2/push_button_out: J1.7; also elsewhere on the board
/push_button_led3/led_in: J1.10; also elsewhere on the board
/push_button_led3/push_button_out: J1.9; also elsewhere on the board
/push_button_led4/led_in: J2.2; also elsewhere on the board
/push_button_led4/push_button_out: J2.1; also elsewhere on the board
/push_button_led5/led_in: J2.4; also elsewhere on the board
/push_button_led5/push_button_out: J2.3; also elsewhere on the board
/push_button_led6/led_in: J2.6; also elsewhere on the board
/push_button_led6/push_button_out: J2.5; also elsewhere on the board
/push_button_led7/led_in: J2.8; also elsewhere on the board
/push_button_led7/push_button_out: J2.7; also elsewhere on the board
/push_button_led/led_in: J1.4; also elsewhere on the board
/push_button_led/push_button_out: J1.3; also elsewhere on the board

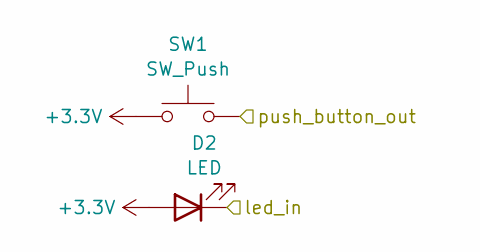
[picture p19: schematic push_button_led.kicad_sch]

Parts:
D2: LED; LED_D3.0mm
SW1: SW_Push; SW_Push_1TS009xxxx-xxxx-xxxx_6x6x5mm

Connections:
+3.3V: D2.2 (A), SW1.1; also elsewhere on the board
/push_button_led1/led_in: D2.1 (K); also elsewhere on the board
/push_button_led/push_button_out: SW1.2; also elsewhere on the board

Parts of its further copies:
D1, D3, D4, D5, D6, D7, D8: LED; LED_D3.0mm
SW2, SW3, SW4, SW5, SW6, SW7, SW8: SW_Push; SW_Push_1TS009xxxx-xxxx-xxxx_6x6x5mm

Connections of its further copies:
+3.3V: D1.2 (A), D3.2 (A), D4.2 (A), D5.2 (A), D6.2 (A), D7.2 (A), D8.2 (A), SW2.1, SW3.1, SW4.1, SW5.1, SW6.1, SW7.1, SW8.1; also elsewhere on the board
/push_button_led1/push_button_out: SW2.2; also elsewhere on the board
/push_button_led2/led_in: D3.1 (K); also elsewhere on the board
/push_button_led2/push_button_out: SW3.2; also elsewhere on the board
/push_button_led3/led_in: D4.1 (K); also elsewhere on the board
/push_button_led3/push_button_out: SW4.2; also elsewhere on the board
/push_button_led4/led_in: D5.1 (K); also elsewhere on the board
/push_button_led4/push_button_out: SW5.2; also elsewhere on the board
/push_button_led5/led_in: D6.1 (K); also elsewhere on the board
/push_button_led5/push_button_out: SW6.2; also elsewhere on the board
/push_button_led6/led_in: D7.1 (K); also elsewhere on the board
/push_button_led6/push_button_out: SW7.2; also elsewhere on the board
/push_button_led7/led_in: D8.1 (K); also elsewhere on the board
/push_button_led7/push_button_out: SW8.2; also elsewhere on the board
/push_button_led/led_in: D1.1 (K); also elsewhere on the board

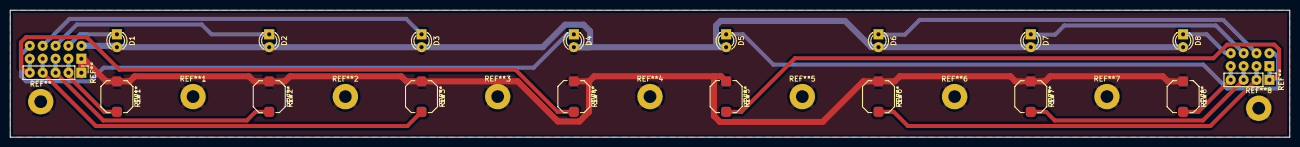
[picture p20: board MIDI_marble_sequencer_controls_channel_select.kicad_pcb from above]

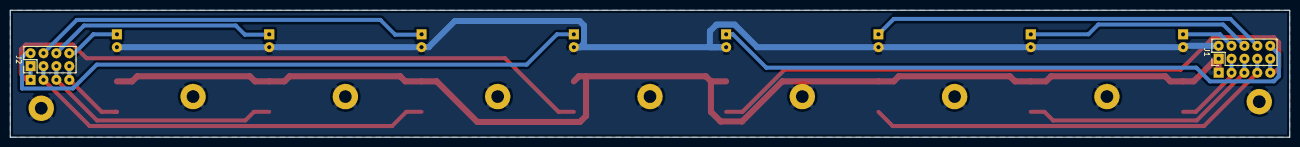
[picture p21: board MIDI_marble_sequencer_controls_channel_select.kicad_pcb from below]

Board: 2 copper layers, 252.0 x 25.0 mm, 18 parts (2 on the bottom side), 17 nets.

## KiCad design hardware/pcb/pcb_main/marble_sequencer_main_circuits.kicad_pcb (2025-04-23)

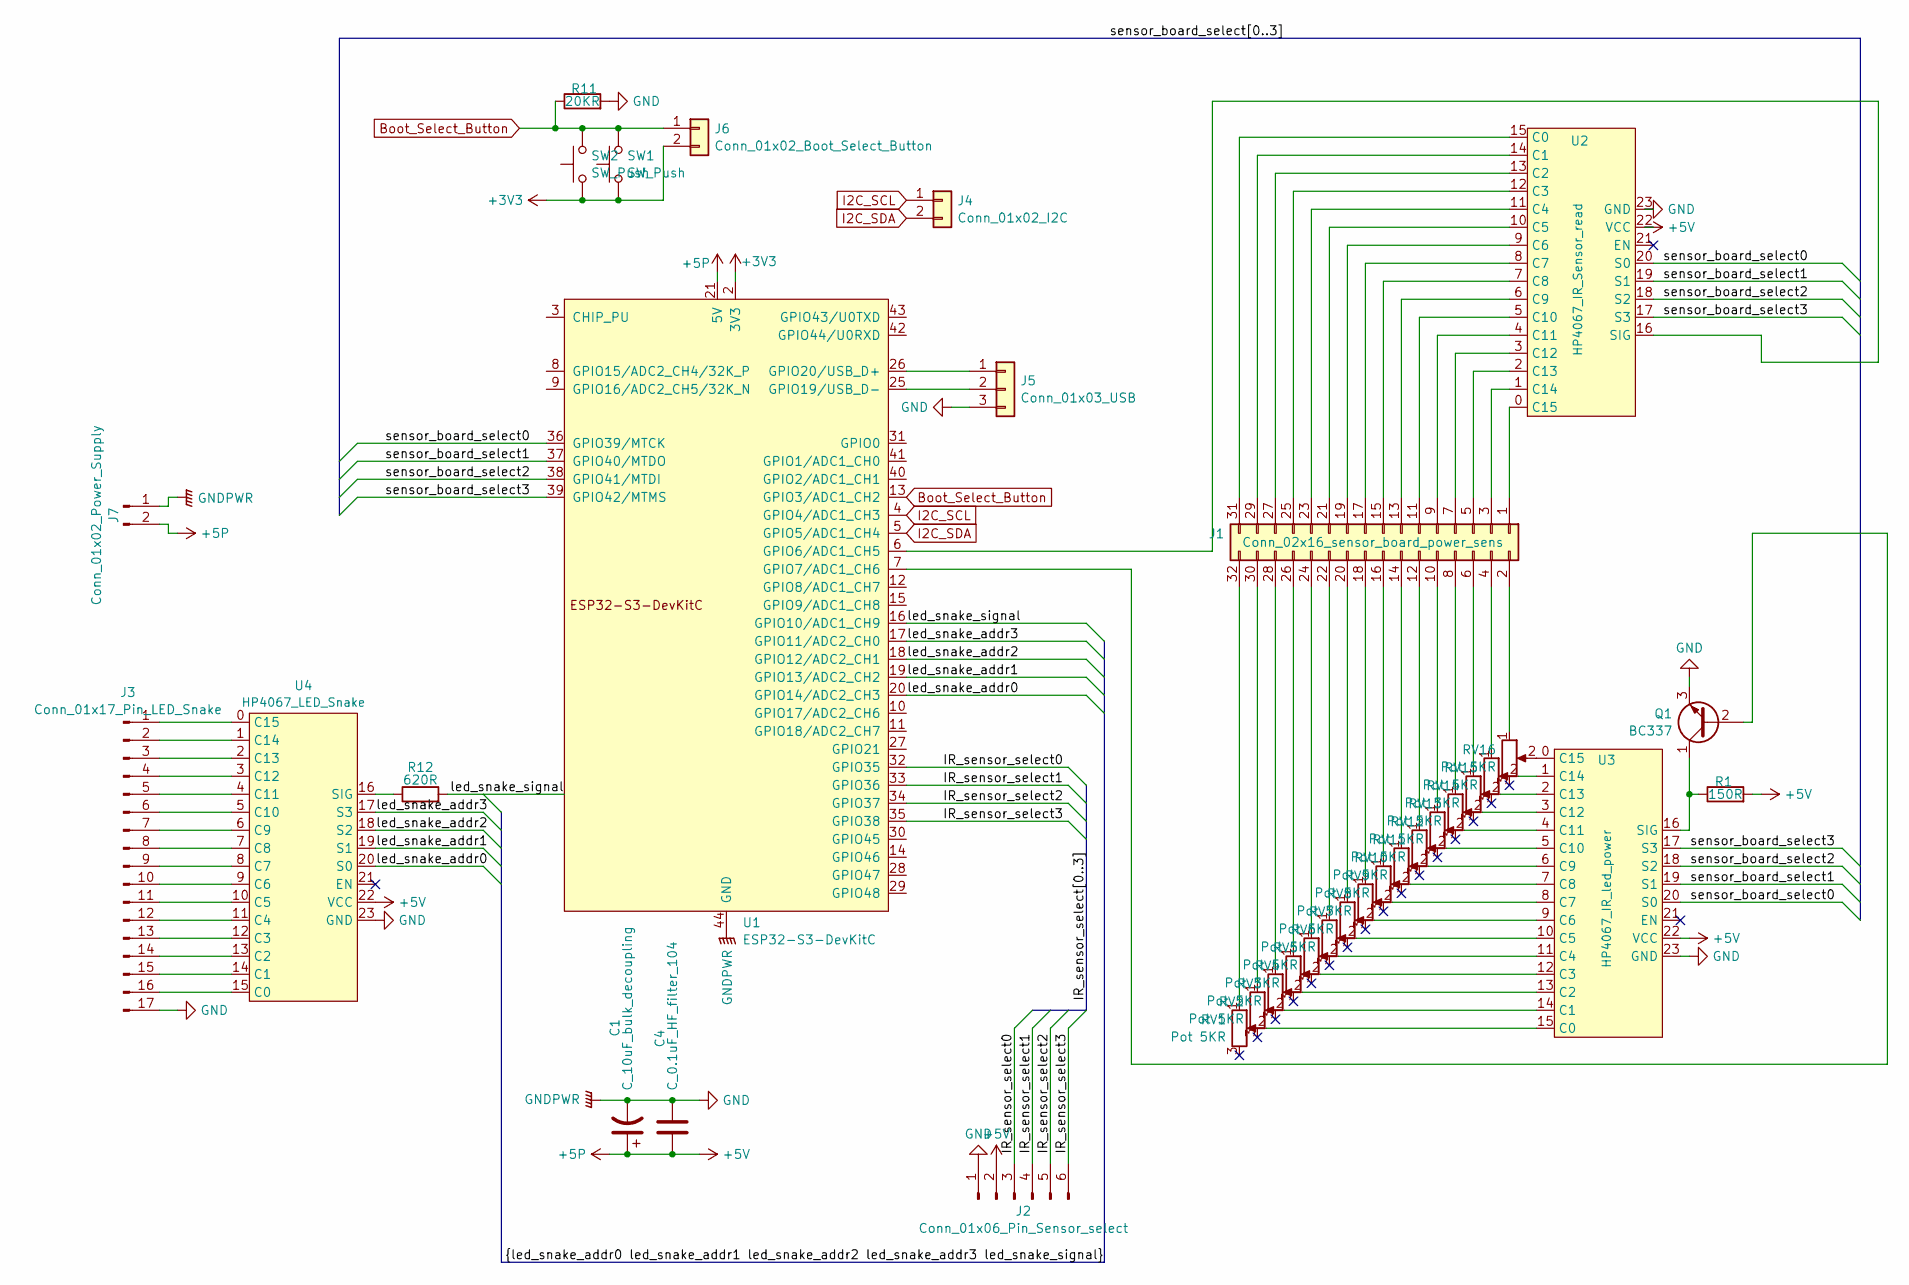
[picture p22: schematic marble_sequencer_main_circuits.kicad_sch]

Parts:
C1: C_10uF_bulk_decoupling; CP_Radial_D8.0mm_P5.00mm
C4: C_0.1uF_HF_filter_104; C_Disc_D5.0mm_W2.5mm_P5.00mm
J1: Conn_02x16_sensor_board_power_sens; PinHeader_2x16_P2.54mm_Vertical
J2: Conn_01x06_Pin_Sensor_select; PhoenixContact_MSTBVA_2,5_6-G-5,08_1x06_P5.08mm_Vertical
J3: Conn_01x17_Pin_LED_Snake; PinHeader_1x17_P2.54mm_Vertical
J4: Conn_01x02_I2C; PhoenixContact_MSTBVA_2,5_2-G-5,08_1x02_P5.08mm_Vertical
J5: Conn_01x03_USB; PhoenixContact_MSTBVA_2,5_3-G-5,08_1x03_P5.08mm_Vertical
J6: Conn_01x02_Boot_Select_Button; PhoenixContact_MSTBVA_2,5_2-G-5,08_1x02_P5.08mm_Vertical
J7: Conn_01x02_Power_Supply; PhoenixContact_MSTBVA_2,5_2-G-5,08_1x02_P5.08mm_Vertical
Q1: BC337; TO-92_Wide
R1: 150R; R_Axial_DIN0617_L17.0mm_D6.0mm_P20.32mm_Horizontal
R11: 20KR; R_Axial_DIN0207_L6.3mm_D2.5mm_P10.16mm_Horizontal_BIG_PADS
R12: 620R; R_Axial_DIN0207_L6.3mm_D2.5mm_P10.16mm_Horizontal_BIG_PADS
RV1, RV2, RV3, RV4, RV5, RV6, RV7, RV8, RV9, RV10, RV11, RV12, RV13, RV14, RV15, RV16: Pot 5KR; Potentiometer_Piher_PT-6-H_Horizontal_Large_Pads
SW1, SW2: SW_Push; SW_Push_1TS009xxxx-xxxx-xxxx_6x6x5mm
U1: ESP32-S3-DevKitC
U2: HP4067_IR_Sensor_read; HP4067_16_ch_analog_mutiplexer_devboard
U3: HP4067_IR_led_power; HP4067_16_ch_analog_mutiplexer_devboard
U4: HP4067_LED_Snake; HP4067_16_ch_analog_mutiplexer_devboard

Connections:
+3V3: J6.2, SW1.1, SW2.1, U1.1 (3V3), U1.2 (3V3)
+5P: C1.1, C4.2, J2.2, J7.2, R1.2, U1.21 (5V), U2.22 (VCC), U3.22 (VCC), U4.22 (VCC)
/IR_sensor_select0: J2.3, U1.32 (GPIO35)
/IR_sensor_select1: J2.4, U1.33 (GPIO36)
/IR_sensor_select2: J2.5, U1.34 (GPIO37)
/IR_sensor_select3: J2.6, U1.35 (GPIO38)
/led_snake_addr0: U1.20 (GPIO14/ADC2_CH3), U4.20 (S0)
/led_snake_addr1: U1.19 (GPIO13/ADC2_CH2), U4.19 (S1)
/led_snake_addr2: U1.18 (GPIO12/ADC2_CH1), U4.18 (S2)
/led_snake_addr3: U1.17 (GPIO11/ADC2_CH0), U4.17 (S3)
/led_snake_signal: R12.2, U1.16 (GPIO10/ADC1_CH9)
/sensor_board_select0: U1.36 (GPIO39/MTCK), U2.20 (S0), U3.20 (S0)
/sensor_board_select1: U1.37 (GPIO40/MTDO), U2.19 (S1), U3.19 (S1)
/sensor_board_select2: U1.38 (GPIO41/MTDI), U2.18 (S2), U3.18 (S2)
/sensor_board_select3: U1.39 (GPIO42/MTMS), U2.17 (S3), U3.17 (S3)
Boot_Select_Button: J6.1, R11.1, SW1.2, SW2.2, U1.13 (GPIO3/ADC1_CH2)
GND: C1.2, C4.1, J2.1, J3.17, J5.3, J7.1, Q1.3 (E), R11.2, U1.22 (GND), U1.23 (GND), U1.24 (GND), U1.44 (GND), U2.23 (GND), U3.23 (GND), U4.23 (GND)
I2C_SCL: J4.1, U1.4 (GPIO4/ADC1_CH3)
I2C_SDA: J4.2, U1.5 (GPIO5/ADC1_CH4)
unnamed: J1.1, U2.0 (C15)
unnamed: J1.2, RV16.1
unnamed: J1.3, U2.1 (C14)
unnamed: J1.4, RV15.1
unnamed: J1.5, U2.2 (C13)
unnamed: J1.6, RV14.1
unnamed: J1.7, U2.3 (C12)
unnamed: J1.8, RV13.1
unnamed: J1.9, U2.4 (C11)
unnamed: J1.10, RV12.1
unnamed: J1.11, U2.5 (C10)
unnamed: J1.12, RV11.1
unnamed: J1.13, U2.6 (C9)
unnamed: J1.14, RV10.1
unnamed: J1.15, U2.7 (C8)
unnamed: J1.16, RV9.1
unnamed: J1.17, U2.8 (C7)
unnamed: J1.18, RV8.1
unnamed: J1.19, U2.9 (C6)
unnamed: J1.20, RV7.1
unnamed: J1.21, U2.10 (C5)
unnamed: J1.22, RV6.1
unnamed: J1.23, U2.11 (C4)
unnamed: J1.24, RV5.1
unnamed: J1.25, U2.12 (C3)
unnamed: J1.26, RV4.1
unnamed: J1.27, U2.13 (C2)
unnamed: J1.28, RV3.1
unnamed: J1.29, U2.14 (C1)
unnamed: J1.30, RV2.1
unnamed: J1.31, U2.15 (C0)
unnamed: J1.32, RV1.1
unnamed: J3.1, U4.0 (C15)
unnamed: J3.2, U4.1 (C14)
unnamed: J3.3, U4.2 (C13)
unnamed: J3.4, U4.3 (C12)
unnamed: J3.5, U4.4 (C11)
unnamed: J3.6, U4.5 (C10)
unnamed: J3.7, U4.6 (C9)
unnamed: J3.8, U4.7 (C8)
unnamed: J3.9, U4.8 (C7)
unnamed: J3.10, U4.9 (C6)
unnamed: J3.11, U4.10 (C5)
unnamed: J3.12, U4.11 (C4)
unnamed: J3.13, U4.12 (C3)
unnamed: J3.14, U4.13 (C2)
unnamed: J3.15, U4.14 (C1)
unnamed: J3.16, U4.15 (C0)
unnamed: J5.1, U1.26 (GPIO20/USB_D+)
unnamed: J5.2, U1.25 (GPIO19/USB_D-)
unnamed: Q1.2 (B), U1.7 (GPIO7/ADC1_CH6)
unnamed: Q1.1 (C), R1.1, U3.16 (SIG)
unnamed: U1.6 (GPIO6/ADC1_CH5), U2.16 (SIG)
unnamed: RV1.2, U3.15 (C0)
unnamed: RV2.2, U3.14 (C1)
unnamed: RV3.2, U3.13 (C2)
unnamed: RV4.2, U3.12 (C3)
unnamed: RV5.2, U3.11 (C4)
unnamed: RV6.2, U3.10 (C5)
unnamed: RV7.2, U3.9 (C6)
unnamed: RV8.2, U3.8 (C7)
unnamed: RV9.2, U3.7 (C8)
unnamed: RV10.2, U3.6 (C9)
unnamed: RV11.2, U3.5 (C10)
unnamed: RV12.2, U3.4 (C11)
unnamed: RV13.2, U3.3 (C12)
unnamed: RV14.2, U3.2 (C13)
unnamed: RV15.2, U3.1 (C14)
unnamed: RV16.2, U3.0 (C15)
unnamed: R12.1, U4.16 (SIG)

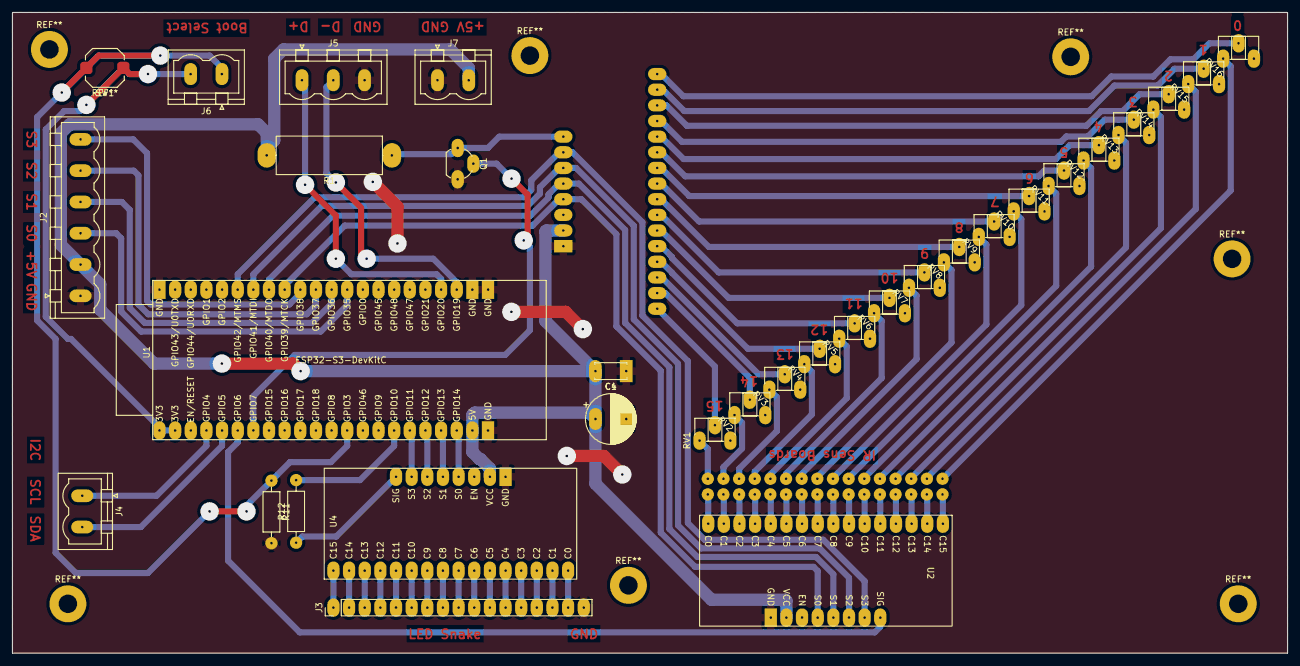
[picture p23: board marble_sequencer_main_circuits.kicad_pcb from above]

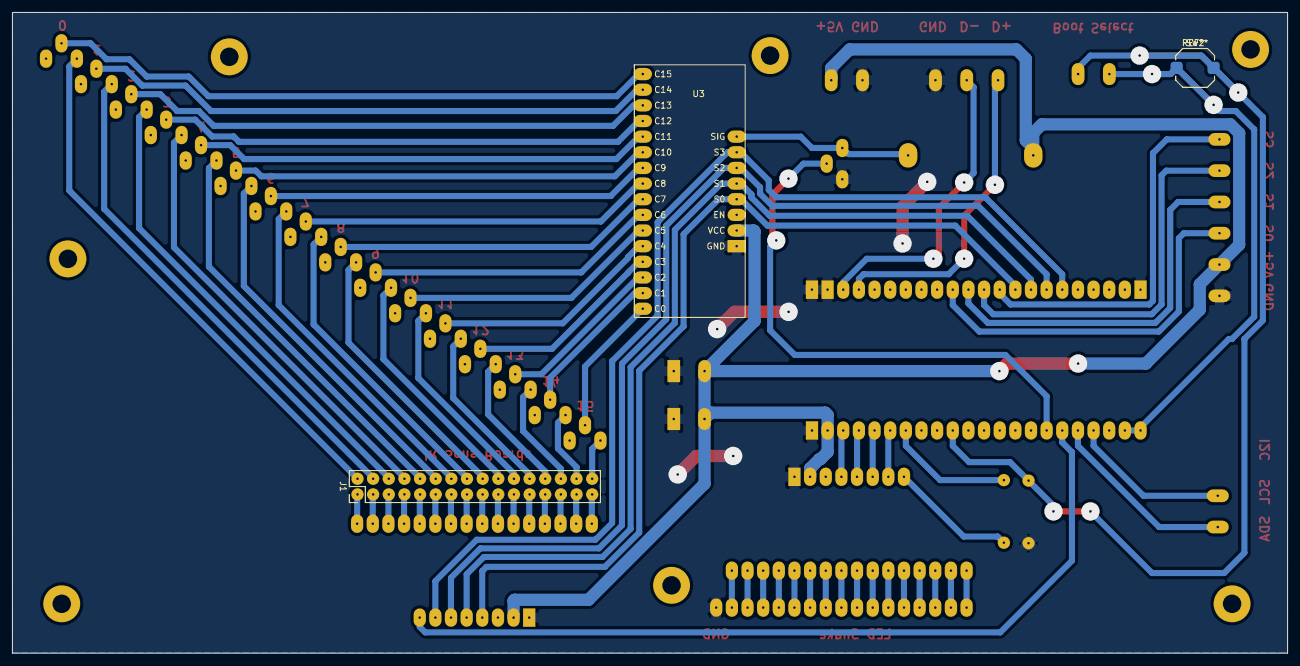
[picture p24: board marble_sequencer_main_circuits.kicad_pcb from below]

Board: 2 copper layers, 207.0 x 104.0 mm, 35 parts (3 on the bottom side), 89 nets.

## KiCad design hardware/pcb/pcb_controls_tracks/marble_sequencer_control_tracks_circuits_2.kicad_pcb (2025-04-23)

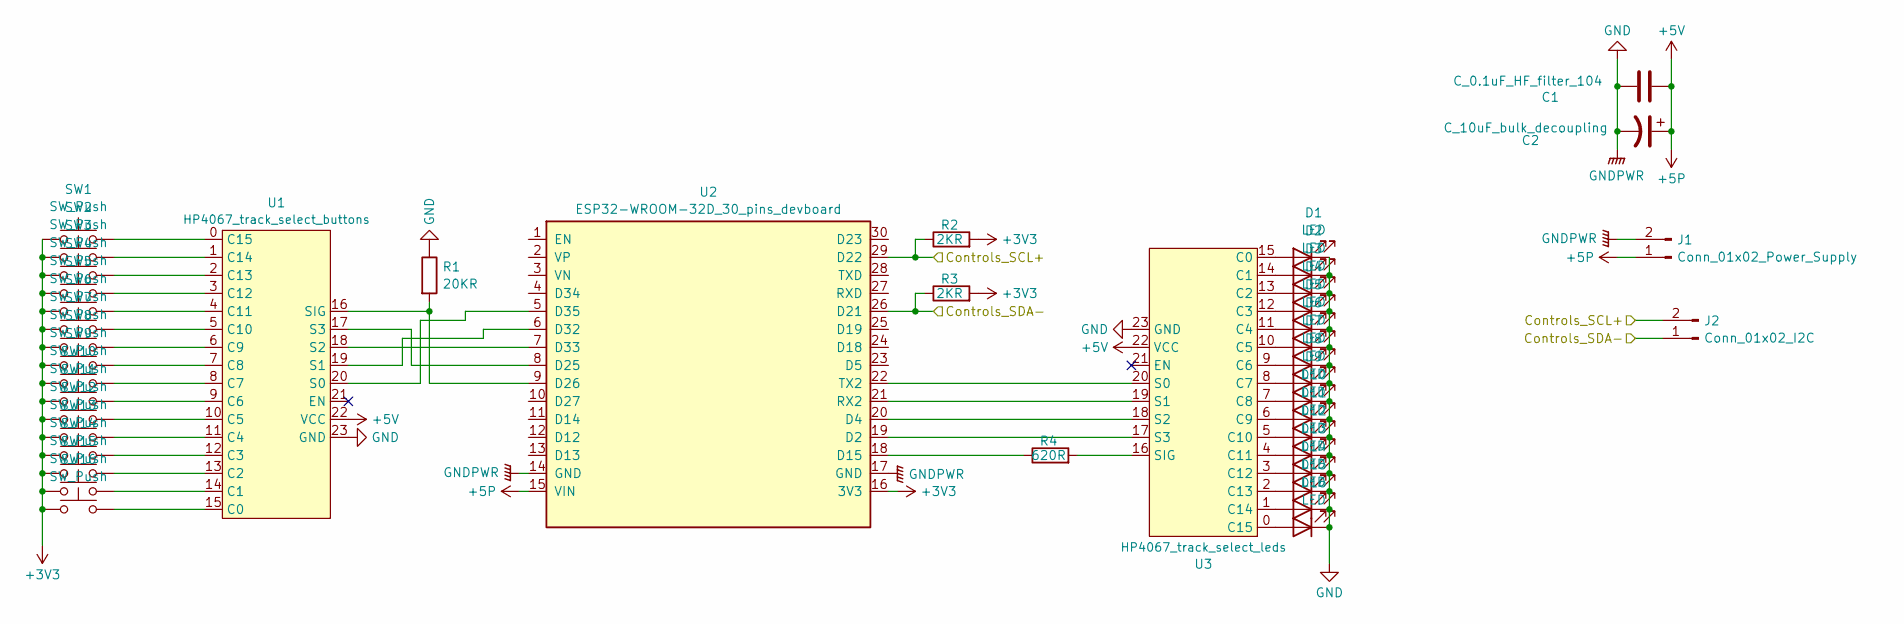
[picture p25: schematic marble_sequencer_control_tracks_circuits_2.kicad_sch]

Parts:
C1: C_0.1uF_HF_filter_104; C_Disc_D5.0mm_W2.5mm_P5.00mm
C2: C_10uF_bulk_decoupling; CP_Radial_D8.0mm_P5.00mm
D1, D2, D3, D4, D5, D6, D7, D8, D9, D10, D11, D12, D13, D14, D15, D16: LED; LED_D3.0mm
J1: Conn_01x02_Power_Supply; PhoenixContact_MSTBVA_2,5_2-G-5,08_1x02_P5.08mm_Vertical
J2: Conn_01x02_I2C; PhoenixContact_MSTBVA_2,5_2-G-5,08_1x02_P5.08mm_Vertical
R1: 20KR; R_Axial_DIN0207_L6.3mm_D2.5mm_P10.16mm_Horizontal_BIG_PADS
R2, R3: 2KR; R_Axial_DIN0207_L6.3mm_D2.5mm_P10.16mm_Horizontal_BIG_PADS
R4: 620R; R_Axial_DIN0207_L6.3mm_D2.5mm_P10.16mm_Horizontal_BIG_PADS
SW1, SW2, SW3, SW4, SW5, SW6, SW7, SW8, SW9, SW10, SW11, SW12, SW13, SW14, SW15, SW16: SW_Push; SW_Push_1TS009xxxx-xxxx-xxxx_6x6x5mm
U1: HP4067_track_select_buttons; HP4067_16_ch_analog_mutiplexer_devboard
U2: ESP32-WROOM-32D_30_pins_devboard
U3: HP4067_track_select_leds; HP4067_16_ch_analog_mutiplexer_devboard

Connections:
+3V3: R2.2, R3.2, SW1.1, SW2.1, SW3.1, SW4.1, SW5.1, SW6.1, SW7.1, SW8.1, SW9.1, SW10.1, SW11.1, SW12.1, SW13.1, SW14.1, SW15.1, SW16.1, U2.16 (3V3)
+5P: C1.2, C2.1, J1.1, U1.22 (VCC), U2.15 (VIN), U3.22 (VCC)
/Controls_SCL: J2.2, R2.1, U2.29 (D22)
/Controls_SDA: J2.1, R3.1, U2.26 (D21)
GND: C1.1, C2.2, D1.1 (K), D2.1 (K), D3.1 (K), D4.1 (K), D5.1 (K), D6.1 (K), D7.1 (K), D8.1 (K), D9.1 (K), D10.1 (K), D11.1 (K), D12.1 (K), D13.1 (K), D14.1 (K), D15.1 (K), D16.1 (K), J1.2, R1.1, U1.23 (GND), U2.14 (GND), U2.17 (GND), U3.23 (GND)
unnamed: D1.2 (A), U3.15 (C0)
unnamed: D2.2 (A), U3.14 (C1)
unnamed: D3.2 (A), U3.13 (C2)
unnamed: D4.2 (A), U3.12 (C3)
unnamed: D5.2 (A), U3.11 (C4)
unnamed: D6.2 (A), U3.10 (C5)
unnamed: D7.2 (A), U3.9 (C6)
unnamed: D8.2 (A), U3.8 (C7)
unnamed: D9.2 (A), U3.7 (C8)
unnamed: D10.2 (A), U3.6 (C9)
unnamed: D11.2 (A), U3.5 (C10)
unnamed: D12.2 (A), U3.4 (C11)
unnamed: D13.2 (A), U3.3 (C12)
unnamed: D14.2 (A), U3.2 (C13)
unnamed: D15.2 (A), U3.1 (C14)
unnamed: D16.2 (A), U3.0 (C15)
unnamed: SW16.2, U1.15 (C0)
unnamed: SW15.2, U1.14 (C1)
unnamed: SW14.2, U1.13 (C2)
unnamed: SW13.2, U1.12 (C3)
unnamed: SW12.2, U1.11 (C4)
unnamed: SW11.2, U1.10 (C5)
unnamed: SW10.2, U1.9 (C6)
unnamed: SW9.2, U1.8 (C7)
unnamed: SW8.2, U1.7 (C8)
unnamed: SW7.2, U1.6 (C9)
unnamed: SW6.2, U1.5 (C10)
unnamed: SW5.2, U1.4 (C11)
unnamed: SW4.2, U1.3 (C12)
unnamed: SW3.2, U1.2 (C13)
unnamed: SW2.2, U1.1 (C14)
unnamed: SW1.2, U1.0 (C15)
unnamed: U1.20 (S0), U2.5 (D35)
unnamed: U1.19 (S1), U2.6 (D32)
unnamed: U1.18 (S2), U2.7 (D33)
unnamed: U1.17 (S3), U2.8 (D25)
unnamed: R1.2, U1.16 (SIG), U2.9 (D26)
unnamed: U2.19 (D2), U3.17 (S3)
unnamed: U2.20 (D4), U3.18 (S2)
unnamed: R4.1, U2.18 (D15)
unnamed: U2.21 (RX2), U3.19 (S1)
unnamed: U2.22 (TX2), U3.20 (S0)
unnamed: R4.2, U3.16 (SIG)

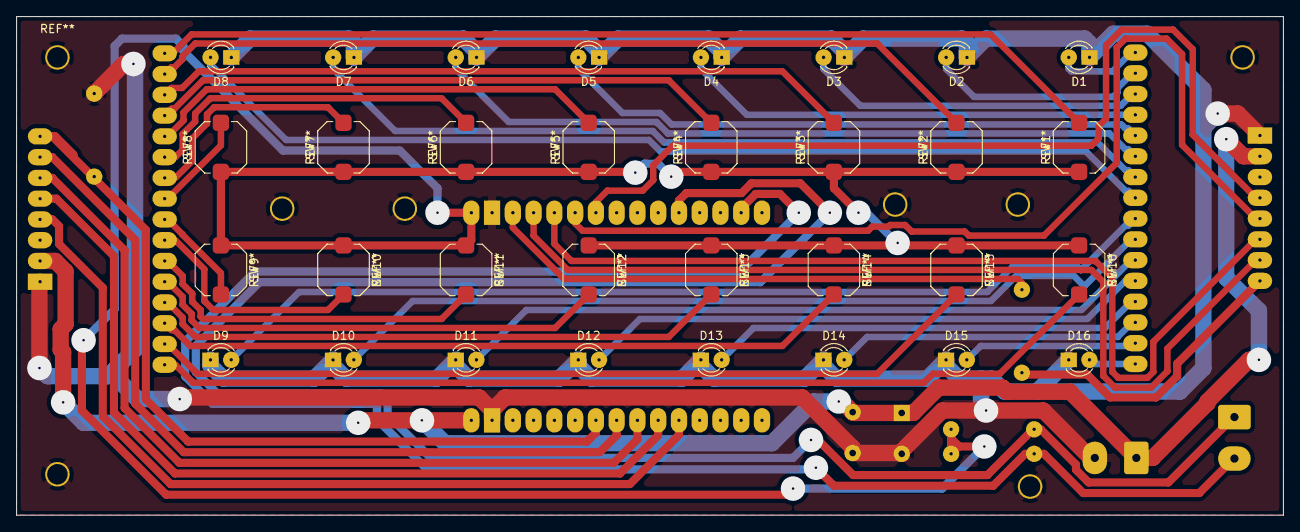
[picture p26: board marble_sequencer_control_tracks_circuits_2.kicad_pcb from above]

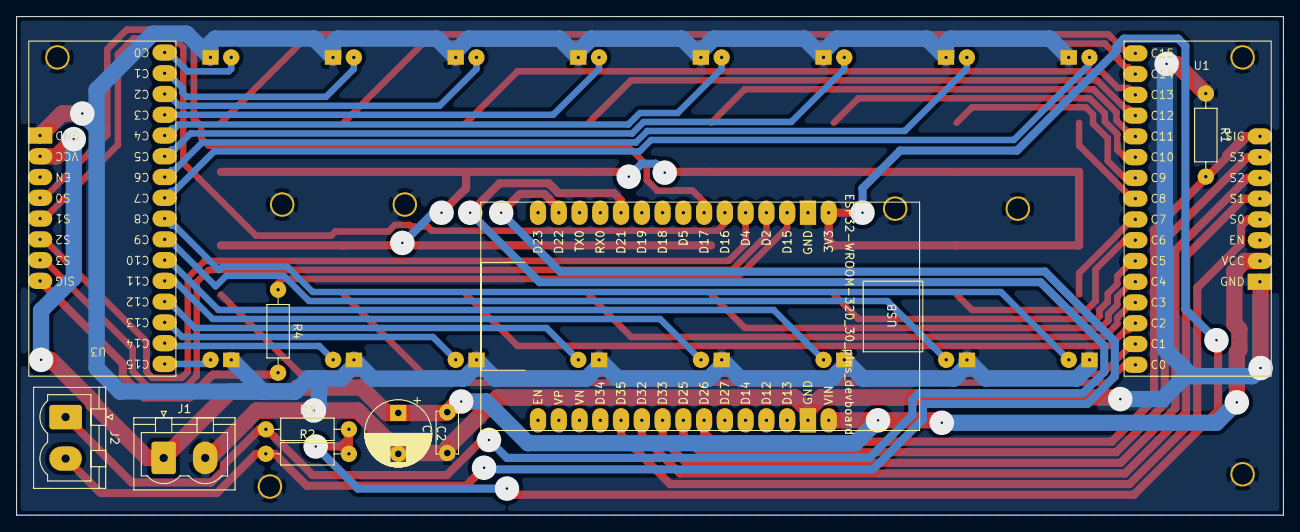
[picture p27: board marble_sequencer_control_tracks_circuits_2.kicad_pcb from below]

Board: 2 copper layers, 155.0 x 61.0 mm, 43 parts (11 on the bottom side), 48 nets.

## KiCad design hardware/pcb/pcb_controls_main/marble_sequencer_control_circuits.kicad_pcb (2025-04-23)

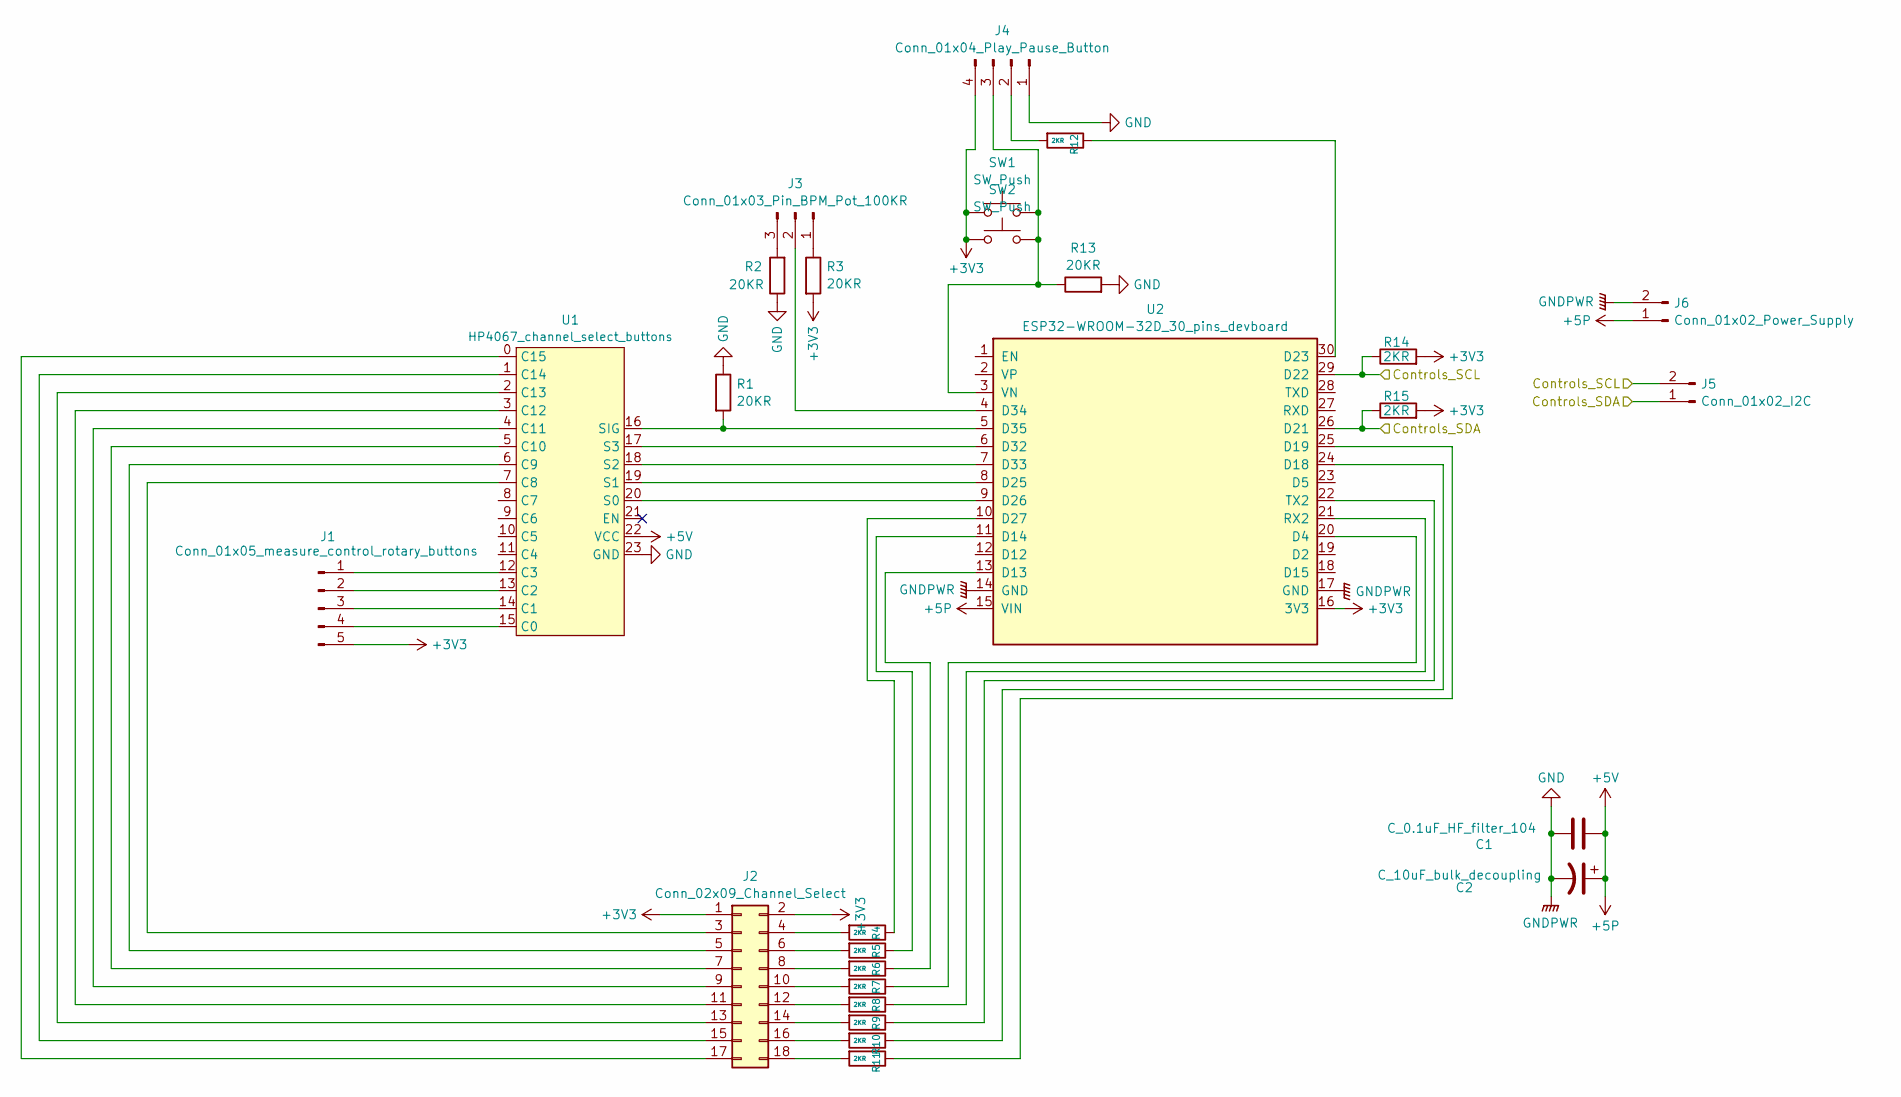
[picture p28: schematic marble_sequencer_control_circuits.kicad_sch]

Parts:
C1: C_0.1uF_HF_filter_104; C_Disc_D5.0mm_W2.5mm_P5.00mm
C2: C_10uF_bulk_decoupling; CP_Radial_D8.0mm_P5.00mm
J1: Conn_01x05_measure_control_rotary_buttons; PinHeader_1x05_P2.54mm_Vertical
J2: Conn_02x09_Channel_Select; PinHeader_2x09_P2.54mm_Vertical
J3: Conn_01x03_Pin_BPM_Pot_100KR; PhoenixContact_MSTBVA_2,5_3-G-5,08_1x03_P5.08mm_Vertical
J4: Conn_01x04_Play_Pause_Button; PhoenixContact_MSTBVA_2,5_4-G-5,08_1x04_P5.08mm_Vertical
J5: Conn_01x02_I2C; PhoenixContact_MSTBVA_2,5_2-G-5,08_1x02_P5.08mm_Vertical
J6: Conn_01x02_Power_Supply; PhoenixContact_MSTBVA_2,5_2-G-5,08_1x02_P5.08mm_Vertical
R1, R2, R3, R13: 20KR; R_Axial_DIN0207_L6.3mm_D2.5mm_P10.16mm_Horizontal_BIG_PADS
R4, R5, R6, R7, R8, R9, R10, R11, R12, R14, R15: 2KR; R_Axial_DIN0207_L6.3mm_D2.5mm_P10.16mm_Horizontal_BIG_PADS
SW1, SW2: SW_Push; SW_Push_1TS009xxxx-xxxx-xxxx_6x6x5mm
U1: HP4067_channel_select_buttons; HP4067_16_ch_analog_mutiplexer_devboard
U2: ESP32-WROOM-32D_30_pins_devboard

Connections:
+3V3: J1.5, J2.1, J2.2, J4.4, R3.2, R14.2, R15.2, SW1.1, SW2.1, U2.16 (3V3)
+5P: C1.2, C2.1, J6.1, U1.22 (VCC), U2.15 (VIN)
/Controls_SCL: J5.2, R14.1, U2.29 (D22)
/Controls_SDA: J5.1, R15.1, U2.26 (D21)
GND: C1.1, C2.2, J4.1, J6.2, R1.1, R2.1, R13.2, U1.23 (GND), U2.14 (GND), U2.17 (GND)
unnamed: J1.1, U1.12 (C3)
unnamed: J1.2, U1.13 (C2)
unnamed: J1.3, U1.14 (C1)
unnamed: J1.4, U1.15 (C0)
unnamed: J2.3, U1.7 (C8)
unnamed: J2.4, R4.2
unnamed: J2.5, U1.6 (C9)
unnamed: J2.6, R5.2
unnamed: J2.7, U1.5 (C10)
unnamed: J2.8, R6.2
unnamed: J2.9, U1.4 (C11)
unnamed: J2.10, R7.2
unnamed: J2.11, U1.3 (C12)
unnamed: J2.12, R8.2
unnamed: J2.13, U1.2 (C13)
unnamed: J2.14, R9.2
unnamed: J2.15, U1.1 (C14)
unnamed: J2.16, R10.2
unnamed: J2.17, U1.0 (C15)
unnamed: J2.18, R11.2
unnamed: J3.1, R3.1
unnamed: J3.2, U2.4 (D34)
unnamed: J3.3, R2.2
unnamed: J4.2, R12.2
unnamed: J4.3, R13.1, SW1.2, SW2.2, U2.3 (VN)
unnamed: U1.20 (S0), U2.9 (D26)
unnamed: U1.19 (S1), U2.8 (D25)
unnamed: U1.18 (S2), U2.7 (D33)
unnamed: U1.17 (S3), U2.6 (D32)
unnamed: R1.2, U1.16 (SIG), U2.5 (D35)
unnamed: R7.1, U2.20 (D4)
unnamed: R6.1, U2.13 (D13)
unnamed: R5.1, U2.11 (D14)
unnamed: R10.1, U2.24 (D18)
unnamed: R11.1, U2.25 (D19)
unnamed: R12.1, U2.30 (D23)
unnamed: R4.1, U2.10 (D27)
unnamed: R8.1, U2.21 (RX2)
unnamed: R9.1, U2.22 (TX2)

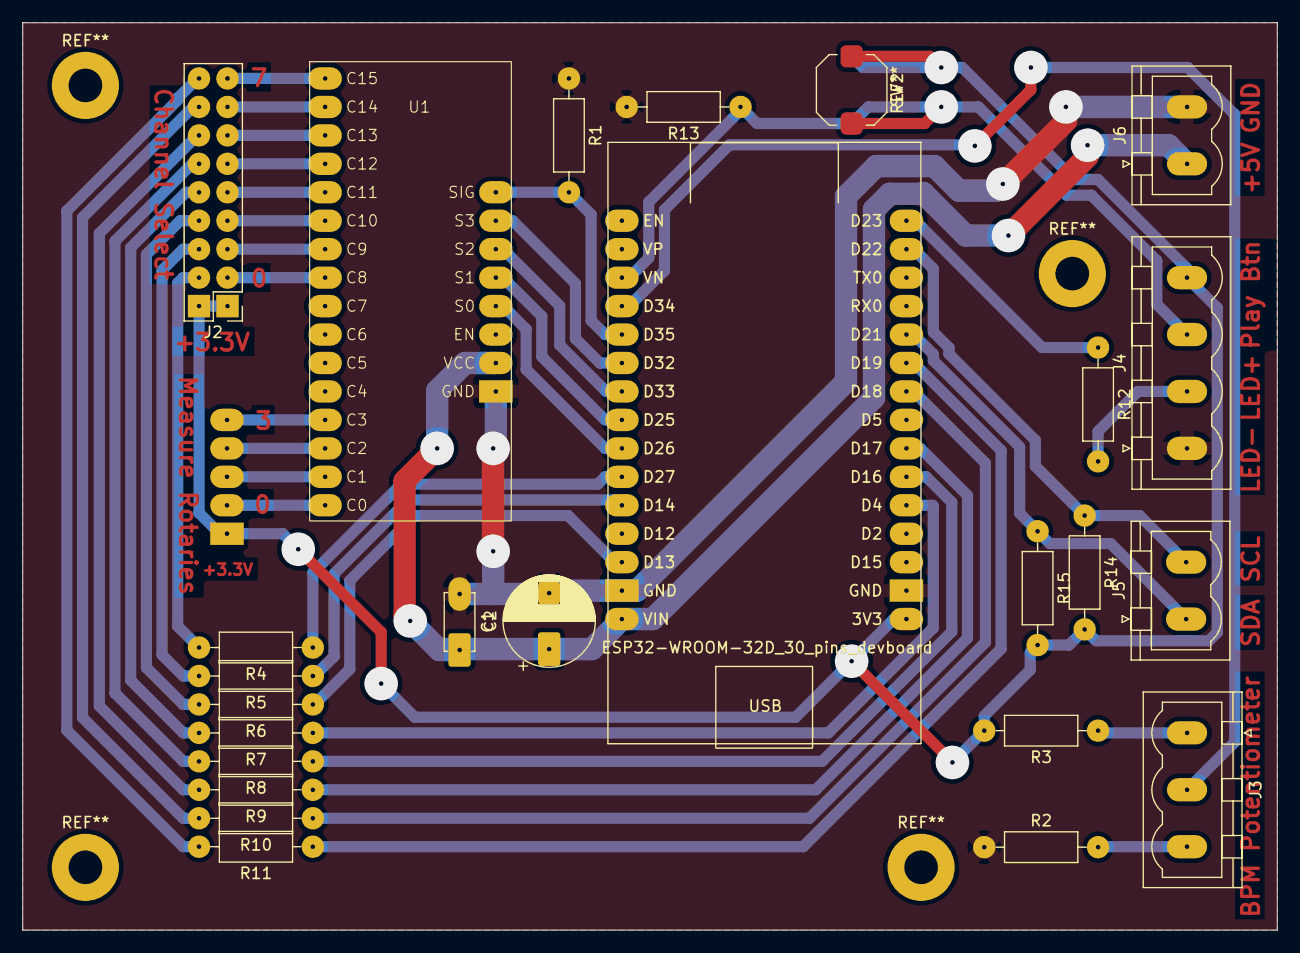
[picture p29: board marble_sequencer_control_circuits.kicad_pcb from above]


Board: 2 copper layers, 112.0 x 81.0 mm, 27 parts (2 on the bottom side), 44 nets.

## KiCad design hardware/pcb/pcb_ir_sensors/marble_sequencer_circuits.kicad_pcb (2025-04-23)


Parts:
J1, J2: Conn_01x06_Pin; PinHeader_1x06_P2.54mm_Vertical
J3: Conn_01x02_Pin; PinHeader_1x02_P2.54mm_Vertical
Q1: BD235; TO-126-3_Vertical
R1, R2, R4, R5, R6, R7, R8, R9, R10, R11, R12, R13, R14, R15, R16, R17, R18, R19, R20, R21, R22, R23, R24, R25, R26, R27, R28, R29, R30, R31, R32, R33: R; R_Axial_DIN0207_L6.3mm_D2.5mm_P10.16mm_Horizontal_BIG_PADS
U1: HP4067_16_ch_analog_mutiplexer_devboard
U2, U3, U4, U5, U6, U7, U8, U9, U10, U11, U12, U13, U14, U15, U16, U17: QRE1113GR

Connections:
+5V: J1.2, J2.2, Q1.2 (C), R1.1, R5.2, R7.2, R9.2, R11.2, R13.2, R15.2, R17.2, R26.2, R27.2, R28.2, R29.2, R30.2, R31.2, R32.2, R33.2, U1.22 (VCC)
/IR_Sens0: R18.2, R26.1, U1.0 (C15), U10.3
/IR_Sens1: R19.2, R27.1, U1.1 (C14), U11.3
/IR_Sens2: R20.2, R28.1, U1.2 (C13), U12.3
/IR_Sens3: R21.2, R29.1, U1.3 (C12), U13.3
/IR_Sens4: R22.2, R30.1, U1.4 (C11), U14.3
/IR_Sens5: R23.2, R31.1, U1.5 (C10), U15.3
/IR_Sens6: R24.2, R32.1, U1.6 (C9), U16.3
/IR_Sens7: R25.2, R33.1, U1.7 (C8), U17.3
/IR_Sens8: R1.2, R2.2, U1.8 (C7), U2.3
/IR_Sens9: R4.2, R5.1, U1.9 (C6), U3.3
/IR_Sens10: R6.2, R7.1, U1.10 (C5), U4.3
/IR_Sens11: R8.2, R9.1, U1.11 (C4), U5.3
/IR_Sens12: R10.2, R11.1, U1.12 (C3), U6.3
/IR_Sens13: R12.2, R13.1, U1.13 (C2), U7.3
/IR_Sens14: R14.2, R15.1, U1.14 (C1), U8.3
/IR_Sens15: R16.2, R17.1, U1.15 (C0), U9.3
GND: J1.1, J2.1, R2.1, R4.1, R6.1, R8.1, R10.1, R12.1, R14.1, R16.1, R18.1, R19.1, R20.1, R21.1, R22.1, R23.1, R24.1, R25.1, U1.23 (GND), U2.2 (K), U2.4, U3.2 (K), U3.4, U4.2 (K), U4.4, U5.2 (K), U5.4, U6.2 (K), U6.4, U7.2 (K), U7.4, U8.2 (K), U8.4, U9.2 (K), U9.4, U10.2 (K), U10.4, U11.2 (K), U11.4, U12.2 (K), U12.4, U13.2 (K), U13.4, U14.2 (K), U14.4, U15.2 (K), U15.4, U16.2 (K), U16.4, U17.2 (K), U17.4
IR_LED_PWR: Q1.1 (E), U2.1 (A), U3.1 (A), U4.1 (A), U5.1 (A), U6.1 (A), U7.1 (A), U8.1 (A), U9.1 (A), U10.1 (A), U11.1 (A), U12.1 (A), U13.1 (A), U14.1 (A), U15.1 (A), U16.1 (A), U17.1 (A)
unnamed: J1.3, J2.3, U1.20 (S0)
unnamed: J1.4, J2.4, U1.19 (S1)
unnamed: J1.5, J2.5, U1.18 (S2)
unnamed: J1.6, J2.6, U1.17 (S3)
unnamed: J3.1, U1.16 (SIG)
unnamed: J3.2, Q1.3 (B)



Board: 2 copper layers, 290.0 x 51.6 mm, 53 parts (37 on the bottom side), 25 nets.

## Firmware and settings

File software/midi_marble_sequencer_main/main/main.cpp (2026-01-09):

#include <freertos/FreeRTOS.h>
#include <freertos/task.h>
#include <esp_log.h>
#include <esp_err.h>
// #include <esp_heap_trace.h>
#include <driver/gpio.h>

#include "IRSensBoards.h"
#include "esp_adc/adc_oneshot.h"
#include "calibration/CalibrationController.h"
#include "BeatsLEDSnake.h"
#include "MasterClock.h"
#include "Sequencer.h"
#include "CalibrationButton.h"

static const char *TAG = "main";



void main_calibrate()
{
    CalibrationController calibration(8, 10, 0);
    // CalibrationController calibration(1, 1, 0);
    while (1)
    {
        calibration.update();
        vTaskDelay(pdMS_TO_TICKS(10));
    }
}


// #define NUM_RECORDS 100
// static heap_trace_record_t trace_record[NUM_RECORDS];

void main_midi_marble_sequencer()
{
    // ESP_ERROR_CHECK( heap_trace_init_standalone(trace_record, NUM_RECORDS) );
    // heap_trace_start(HEAP_TRACE_ALL);

    CalibrationButton &calibration_button = CalibrationButton::instance();
    calibration_button.start_listening_clicks();
    calibration_button.update();
    if (calibration_button.is_down()) {
        ESP_LOGI(TAG, "Calibration button is down at startup, waiting for release before entering calibration mode");
        
        // Wait for button to be released
        while (calibration_button.is_down()) {
            calibration_button.update();
            vTaskDelay(pdMS_TO_TICKS(10));
        }
        
        ESP_LOGI(TAG, "Calibration button released, entering calibration mode");
        main_calibrate();
    }
    else {
        ESP_LOGI(TAG, "Calibration button is up at startup, entering normal mode");
        
        Sequencer sequencer;
        MasterClock master_clock(sequencer);
        vTaskSuspend(NULL); // Suspend main task to let other tasks run
    }

    


    // heap_trace_stop();
    // if (!heap_caps_check_integrity_all(true))
    // {
    //     heap_trace_dump();
    // }

    // while (1)
    // {
    //     // esp_timer_dump(stdout);
    //     // vTaskDelay(pdMS_TO_TICKS(1000));
    // }
}

// void main_test_calibration()
// {
//     CalibrationTest calibration_test(100, 1, 25, 4);
//     while (1)
//     {
//         calibration_test.update();
//         vTaskDelay(pdMS_TO_TICKS(10));
//     }
// }

void print_board_values(uint32_t *values_off, uint32_t *values_on, uint8_t ir_sens_on_board)
{
    for (int i = 0; i < ir_sens_on_board; i++)
    {
        // printf(">on%d: %d\n", i, values_on[i]);
        // printf(">off%d: %d\n", i, values_off[i]);
        printf(">diff%d: %lu\n", i, values_off[i] - values_on[i]);
    }
}

void main_print_values()
{
    IRSensBoards ir_sens_boards;
    IRSensReader board_reader(&ir_sens_boards);

    uint32_t values_on[NUM_IR_SENS_BY_BOARD];
    uint32_t values_off[NUM_IR_SENS_BY_BOARD];

    // uint64_t read_count = 0;
    while (1)
    {
        board_reader.read_board_values(values_off, values_on, 12, 10);

        print_board_values(values_off, values_on, NUM_IR_SENS_BY_BOARD);
        vTaskDelay(pdMS_TO_TICKS(200));
        // if (read_count > 10) {
        //     statistics(values_off, values_on, &ir_sens_board, 100);
        //     distribution(values_off, values_on, 0, &ir_sens_board, 100);
        // }
    }
}

void main_print_all_boards_first_values()
{
    IRSensBoards ir_sens_boards;
    IRSensReader board_reader(&ir_sens_boards);

    uint32_t value_off, value_on;

    while (1)
    {
        for (size_t i = 0; i < NUM_IR_SENS_BOARDS; i++)
        {
            board_reader.read_sensor_value(&value_off, &value_on, i, 0, 10);
            printf(">diff%d: %lf\n", i, (double) value_off - (double) value_on);
        }
        // board_reader.read_sensor_value(&value_off, &value_on, 4, 0, 10);
        // printf(">diff%d: %lf\n", 4, (double) value_off - (double) value_on);

        vTaskDelay(pdMS_TO_TICKS(200));
    }
}

void main_print_15_7_values()
{
    IRSensBoards ir_sens_boards;
    IRSensReader board_reader(&ir_sens_boards);

    uint32_t values_on[NUM_IR_SENS_BY_BOARD];
    uint32_t values_off[NUM_IR_SENS_BY_BOARD];

    // uint64_t read_count = 0;
    while (1)
    {
        board_reader.read_board_values(values_off, values_on, 0, 4);

        printf(">ref15: %ld\n", (int32_t)values_off[15] - (int32_t)values_on[15]);
        printf(">7: %ld\n", (int32_t)values_off[7] - (int32_t)values_on[7]);
        vTaskDelay(pdMS_TO_TICKS(500));
        // if (read_count > 10) {
        //     statistics(values_off, values_on, &ir_sens_board, 100);
        //     distribution(values_off, values_on, 0, &ir_sens_board, 100);
        // }
    }
}

void main_test_led_snake()
{
    BeatsLEDSnake led_snake;

    while (1)
    {
        for (size_t i = 0; i < NUM_IR_SENS_BOARDS; i++)
        {
            led_snake.set_eighth_note_index(i * 2);
            led_snake.update();
            vTaskDelay(pdMS_TO_TICKS(600));
        }
    }
}

// void main_calibration_stats_test()
// {
//     uint16_t (*old)[NUM_IR_SENS_BY_BOARD][NUM_MARBLE_TYPE - 1] = marble_types_thresholds_old;
//     uint16_t (*newt)[NUM_IR_SENS_BY_BOARD][NUM_MARBLE_TYPE - 1] = marble_types_thresholds_new;
//     int16_t max_diff = 0;
//     uint64_t total_diff = 0;

//     for (int board = 0; board < NUM_IR_SENS_BOARDS; board++)
//     {
//         for (int sensor = 0; sensor < NUM_IR_SENS_BY_BOARD; sensor++)
//         {
//             for (int type = 0; type < NUM_MARBLE_TYPE - 1; type++)
//             {
//                 int16_t diff = abs(old[board][sensor][type] - newt[board][sensor][type]);

//                 if (diff > max_diff)
//                 {
//                     max_diff = diff;
//                     printf("Max threshold difference between old and new: %d [%u][%u][%u]\n", max_diff, board, sensor, type);
//                 }

//                 total_diff += diff;
//             }
//         }
//     }

//     printf("Max threshold difference between old and new: %d\n", max_diff);
//     printf("Mean threshold difference between old and new: %lld\n", total_diff / (NUM_IR_SENS_BOARDS * NUM_IR_SENS_BY_BOARD * (NUM_MARBLE_TYPE - 1)));

//     int16_t min_interval = 10000;
//     int64_t total_interval = 0;

//     for (int board = 0; board < NUM_IR_SENS_BOARDS; board++)
//     {
//         for (int sensor = 0; sensor < NUM_IR_SENS_BY_BOARD; sensor++)
//         {
//             for (int type = 0; type < NUM_MARBLE_TYPE - 2; type++)
//             {
//                 int16_t interval = newt[board][sensor][type + 1] - newt[board][sensor][type];
//                 total_interval += interval;

//                 if (min_interval > interval)
//                 {
//                     min_interval = interval;
                    
//                     printf("Min interval: %d [%u][%u][%u]\n", min_interval, board, sensor, type);
//                 }
//             }
//         }
//     }

//     printf("Min interval: %d\n", min_interval);
//     printf("Mean interval: %lld\n", total_interval / (NUM_IR_SENS_BOARDS * NUM_IR_SENS_BY_BOARD * (NUM_MARBLE_TYPE - 2)));
// }

extern "C" void app_main()
{
    main_midi_marble_sequencer();

    // main_test_led_snake();

    // main_print_values();

    // main_print_15_7_values();

    // main_print_all_boards_first_values();

    // main_calibrate();

    // main_test_calibration();
}

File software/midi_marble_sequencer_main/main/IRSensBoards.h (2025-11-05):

#pragma once

#include <driver/gpio.h>
#include <hal/adc_types.h>
#include <CD74HC4067_espidf.h>

#define NUM_IR_SENS_BOARDS 16

#define IR_SENS_BOARD_MUX_S0_PIN GPIO_NUM_39
#define IR_SENS_BOARD_MUX_S1_PIN GPIO_NUM_40
#define IR_SENS_BOARD_MUX_S2_PIN GPIO_NUM_41
#define IR_SENS_BOARD_MUX_S3_PIN GPIO_NUM_42

// ESP-32-S3 GPIO 4
#define IR_SENS_ADC_UNIT ADC_UNIT_1
#define IR_SENS_ADC_CHANNEL ADC_CHANNEL_5

#define IR_LED_POWER_PIN GPIO_NUM_7


#define NUM_IR_SENS_BY_BOARD 16

#define IR_SENS_MUX_S0_PIN GPIO_NUM_35
#define IR_SENS_MUX_S1_PIN GPIO_NUM_36
#define IR_SENS_MUX_S2_PIN GPIO_NUM_37
#define IR_SENS_MUX_S3_PIN GPIO_NUM_38

class IRSensBoards
{
public:
    IRSensBoards();

    void disable_leds();

    void enable_leds();

    void select_board(uint8_t board_index);
    void select_sensor(uint8_t sensor_index);

    static const uint8_t ir_sens_on_board;
    static const adc_unit_t adc_unit = IR_SENS_ADC_UNIT;
    static const adc_channel_t adc_channel = IR_SENS_ADC_CHANNEL;

private:
    CD74HC4067 _ir_sens_board_mux;
    CD74HC4067 _ir_sens_mux;

    uint8_t _selected_board;
    uint8_t _selected_sensor;

    void _init_leds();
};

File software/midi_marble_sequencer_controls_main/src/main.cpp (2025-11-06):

#include "BPMPotentiometer.h"
#include "I2CSlaveController.h"
#include "InteractionController.h"
#include "DisplayController.h"

#include <freertos/FreeRTOS.h>
#include <freertos/task.h>
#include <Arduino.h>

void i2c_slave_controller_task(void *i2c_slave_controller_arg)
{
    I2CSlaveController *i2c_slave_controller = (I2CSlaveController *)i2c_slave_controller_arg;
    i2c_slave_controller->main_task();
}

void main_test_leds()
{
    LEDColumn led_column;
    PlayPauseBPMLED play_pause_led;

    while (1)
    {
        for (size_t i = 0; i < 8; i++)
        {
            vTaskDelay(pdMS_TO_TICKS(600));
            if (i % 2 == 0) {
                play_pause_led.enable();
            }
            else {
                play_pause_led.disable();
            }
            led_column.disable_all_leds();
            led_column.enable_led(i);
        }
    }
}

DisplayController *display_controller = new DisplayController();
InteractionController *interaction_controller = new InteractionController();
I2CSlaveController *i2c_slave_controller = new I2CSlaveController(interaction_controller, display_controller);

void setup()
{
    TaskHandle_t i2c_task_handle;
    xTaskCreate(i2c_slave_controller_task, "I2CSlaveController", 10000, i2c_slave_controller, 1, &i2c_task_handle);

    interaction_controller->set_event_listener(i2c_slave_controller);
    interaction_controller->update();
    i2c_slave_controller->write_to_buffer();
}

void loop()
{
    interaction_controller->update();
}

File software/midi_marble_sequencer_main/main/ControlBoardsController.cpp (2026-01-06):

#include "ControlBoardsController.h"

#include "crc.h"

#include <cstring>
#include <esp_err.h>
#include <esp_log.h>
#include <esp_timer.h>
#include <freertos/FreeRTOS.h>
#include <freertos/task.h>

static const char *TAG = "ControlBoardsController";

static void _main_task_cb(void *control_boards_controller_arg)
{
    ControlBoardsController *control_boards_controller = (ControlBoardsController *)control_boards_controller_arg;
    control_boards_controller->main_task();
}

static void _display_only_task_cb(void *control_boards_controller_arg)
{
    ControlBoardsController *control_boards_controller = (ControlBoardsController *)control_boards_controller_arg;
    control_boards_controller->display_only_task();
}

ControlBoardsController::ControlBoardsController(IControlBoardsListener &listener) : _listener(listener)
{
    i2c_master_bus_config_t i2c_master_config = {
        .i2c_port = I2C_CONFIG_PORT,
        .sda_io_num = I2C_MASTER_SDA_GPIO,
        .scl_io_num = I2C_MASTER_SCL_GPIO,
        .clk_source = I2C_CLK_SRC_DEFAULT,
        .glitch_ignore_cnt = 7,
        .intr_priority = 0,
        // .trans_queue_depth = 128,
        .flags = {
            .enable_internal_pullup = false,
            .allow_pd = false,
        }
    };

    ESP_ERROR_CHECK(i2c_new_master_bus(&i2c_master_config, &_i2c_bus_handle));

    _init_main_controls_i2c();
    _init_pages_controls_i2c();
}

void ControlBoardsController::_init_main_controls_i2c()
{
    i2c_device_config_t controls_main_device_config = {
        .dev_addr_length = I2C_ADDR_BIT_LEN_7,
        .device_address = I2C_CONFIG_CONTROLS_MAIN_ADDR,
        .scl_speed_hz = I2C_CONFIG_CLOCK_SPEED_HZ,
        .scl_wait_us = 5000,
        .flags = {
            .disable_ack_check = true
        }
    };

    ESP_ERROR_CHECK(i2c_master_bus_add_device(_i2c_bus_handle, &controls_main_device_config, &_controls_main_device_handle));
}

void ControlBoardsController::_init_pages_controls_i2c()
{
    i2c_device_config_t controls_pages_device_config = {
        .dev_addr_length = I2C_ADDR_BIT_LEN_7,
        .device_address = I2C_CONFIG_CONTROLS_PAGES_ADDR,
        .scl_speed_hz = I2C_CONFIG_CLOCK_SPEED_HZ,
        .scl_wait_us = 0,
        .flags = {
            .disable_ack_check = true
        }
    };

    ESP_ERROR_CHECK(i2c_master_bus_add_device(_i2c_bus_handle, &controls_pages_device_config, &_controls_pages_device_handle));
}

void ControlBoardsController::start_main_task()
{
    TaskHandle_t control_boards_task_handle;
    xTaskCreate(_main_task_cb, "ControlBoardsController main", 3500, this, 1, &control_boards_task_handle);
}

void ControlBoardsController::start_display_only_task()
{
    TaskHandle_t control_boards_task_handle;
    xTaskCreate(_display_only_task_cb, "ControlBoardsController display_only", 3500, this, 1, &control_boards_task_handle);
}

void ControlBoardsController::main_task()
{
    while (true)
    {
        _talk_to_controls_main();
        _talk_to_controls_pages();
        vTaskDelay(pdMS_TO_TICKS(I2C_CONFIG_TRANSACTION_DELAY_US / 1000));
    }
}

void ControlBoardsController::display_only_task()
{
    esp_err_t err;

    while (true)
    {
        do {
            err = _transmit_controls_main_display(_get_controls_main_display());
        } while (err != ESP_OK);

        do {
            err = _transmit_controls_pages_display(_get_controls_pages_display());
        } while (err != ESP_OK);

        vTaskDelay(pdMS_TO_TICKS(I2C_CONFIG_TRANSACTION_DELAY_US / 1000));
    }
}

void ControlBoardsController::_talk_to_controls_main()
{
    esp_err_t err;

    do {
        err = _read_controls_main_events();
    } while (err != ESP_OK);

    do {
        err = _transmit_controls_main_display(_get_controls_main_display());
    } while (err != ESP_OK);
}

esp_err_t ControlBoardsController::_read_controls_main_events()
{
    esp_err_t err = ESP_OK;

    controls_main_value_t controls_main_value;
    err = i2c_master_receive(_controls_main_device_handle, (uint8_t *) &controls_main_value, sizeof(controls_main_value_t), -1);

    if (err != ESP_OK)
    {
        ESP_LOGE(TAG, "controls_main receive err: %x", err);
        return err;
    }

    if (!check_crc16((uint8_t *) &controls_main_value, sizeof(controls_main_value_t)))
    {
        err = ESP_ERR_INVALID_CRC;
        ESP_LOGE(TAG, "controls_main CRC check FAILED!");
        return err;
    }

    _listener.handle_controls_main_event(controls_main_value);
    _last_controls_main_value = controls_main_value;

    return err;
}

static uint8_t _push_buttons_events_to_consumed_clicks(uint16_t push_buttons_events, const uint8_t num_buttons)
{
    uint8_t consumed_clicks = 0;

    for (size_t i = num_buttons; i > 0; i--)
    {
        // odd number of clicks consumed
        if (push_buttons_events & 0x2)
        {
            consumed_clicks = consumed_clicks | 0x80;
        }

        if (i <= 1)
        {
            break;
        }

        push_buttons_events = push_buttons_events >> 2;
        consumed_clicks = consumed_clicks >> 1;
    }
    
    return consumed_clicks;
}

esp_err_t ControlBoardsController::_transmit_controls_main_display(controls_main_display_t controls_main_display)
{
    esp_err_t err = ESP_OK;

    memcpy(_main_write_buffer, &controls_main_display, sizeof(controls_main_display_t));
    compute_crc16(_main_write_buffer, sizeof(controls_main_display_t));

    err = i2c_master_transmit(_controls_main_device_handle, _main_write_buffer, sizeof(controls_main_display_t), -1);

    if (err != ESP_OK)
    {
        ESP_LOGE(TAG, "controls_main transmit err: %x", err);
        return err;
    }

    return err;
}

controls_main_display_t ControlBoardsController::_get_controls_main_display()
{
    controls_main_display_t controls_main_display = _listener.get_controls_main_display();

    controls_main_display.tracks_buttons_clicks_consumed = _push_buttons_events_to_consumed_clicks(_last_controls_main_value.tracks_push_buttons, SEQUENCER_TRACKS_NUM);

    return controls_main_display;
}

void ControlBoardsController::_talk_to_controls_pages()
{
    esp_err_t err;

    do {
        err = _read_controls_pages_events();
    } while (err != ESP_OK);

    do {
        err = _transmit_controls_pages_display(_get_controls_pages_display());
    } while (err != ESP_OK);
}
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

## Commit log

2025-04-23 Base code for main esp32. LED Snake example running.
    [analytics.ods]
2025-04-25 Base code for multiple IR Sensor boards + code to print first sensor of each board to calibrate LEDs power for each board using the potentiometers.
2025-07-22 Calibration and base midi controller code.
    [0.csv, 1.csv, 2.csv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]
2025-07-23 Classes for each physical actuator managed by main controls board.
2025-07-26 i2c communication between main and controls_main.
2025-07-28 BPM Timer and SequencerPage notions.
2025-07-29 Measure states updated. SKIP state works. LED Snake don't use blink scheme anymore.
    [ControlBoardsController.cpp, main.cpp]
2025-07-29 Make i2c communication more reliable.
2025-07-30 Calibration change threshold computation.
2025-07-30 New calibration data.
    [calibration_3_marbles.csv]
2025-07-31 Add CRC check for i2c transactions.
2025-07-31 Tracks mute buttons work.
2025-10-17 Clean PCB repo.
    [freerouting.dsn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]
2025-10-17 Clean software directory. Delete old code.
    [0.csv, 1.csv, 2.csv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]
2025-11-05 First correct communication between main and controls_main. ESP-IDF i2c slave driver is garbage: had to use arduinoesp32 framework instead.
    [BPMPotentiometer.cpp, CD74HC4067_espidf.cpp, ControlBoardsController.cpp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]
2025-11-05 i2c communication between esp32 boards working.
2025-11-06 BPM displayed on play/pause LED.
2025-11-10 Calibration procedure with LED display. Calibration data saved and retreived from Non Volatile Storage (NVS).
2025-11-11 Statistics for sensor distribution.
    [quick_13.ods, sensor_distribution.ods]
2025-11-13 Current page LED blink. Start of page handling.
2025-11-14 Restart blink clock when changing blinking led.
2025-11-14 Blink current playing page even when it is programmed to stop playing afterwards.
2025-12-19 Flight case blueprint.
    [bord_av_m_ar_g.SLDPRT, corniere.SLDPRT, corniere_ar_l_ar_b.SLDPRT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]
2025-12-20 Calibration guide.
2026-01-08 Fix some bugs in Calibration and handle sensor boundaries saturation.
    [quick_13.ods, sensor_distribution.ods]
2026-01-09 New phase of calibration before sensor calibration: board calibration.
